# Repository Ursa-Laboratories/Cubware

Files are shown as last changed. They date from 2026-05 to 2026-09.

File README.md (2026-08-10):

# Cubware

Cubware is the repository for 3D-printed STL and design files for the open
source **Cub** and **CubOS** ecosystem. It holds the printable meshes,
source CAD (`.step`), preview assets, and any per-part documentation needed
to fabricate hardware for a Cub system.

## Configurations

Cub systems are built on top of an off-the-shelf SainSmart PROVER CNC
gantry. Cubware supports three configurations, and the repository is
organized by configuration:

| Configuration | Directory | Gantry hardware | Purpose |
| --- | --- | --- | --- |
| **Cub** | [`cub/`](cub/) | SainSmart PROVER 3030 | Single-instrument characterization. |
| **CubXL** | [`cubxl/`](cubxl/) | SainSmart PROVER 4030XL | Indentation experiments with a force sensor (ASMI) — see [ASMI_new](https://github.com/BU-KABlab/ASMI_new). |
| **CubXL+** | [`cubxl_plus/`](cubxl_plus/) | SainSmart PROVER 4030XL | Non-contact multi-instrument deck (PANDA) — see [PANDA-BEAR](https://github.com/BU-KABlab/PANDA-BEAR). |

## Layout

```
Cubware/
├── cub/                    # Cub (PROVER 3030)
│   ├── instrument_mounts/  #   uv_vis/, asmi/
│   └── labware/            #   well_plate_holder/, calibration_block/
├── cubxl/                  # CubXL (PROVER 4030XL, ASMI)
│   ├── instrument_mounts/  #   asmi/
│   └── labware/            #   well_plate_holder/, calibration_block/
├── cubxl_plus/             # CubXL+ (PROVER 4030XL, PANDA)
│   ├── deck/               #   polycarbonate_deck/
│   ├── instrument_mounts/  #   backboard/, vial_capper_decapper_mount/,
│   │                       #   raspberry_pi_mount/, potentiostat_mount/
│   └── labware/            #   well_plate_holder/, calibration_block/,
│                           #   vial_holder/, tip_rack_holder/
├── shared/                 # Parts used by every configuration
│                           #   (calibration_block/)
├── misc/                   # Parts not yet assigned to a configuration
├── documentation/          # Build guides and hardware assembly notes
├── tools/                  # CAD generation / QA scripts (FreeCAD)
└── scripts/                # Preview rendering helpers
```

Each part lives in its own folder so that it can carry its own README,
preview images, source CAD, and any other documentation it needs. Parts
shared by all three configurations (like the calibration block) live once
under `shared/`, with pointer READMEs in each configuration's tree.

## Folder conventions

Inside each part folder you may find:

| File | Purpose |
| --- | --- |
| `*.stl` | Printable mesh — what you send to the slicer. |
| `*.step` | Source CAD — editable in any parametric CAD tool. |
| `*.glb` | Web/local 3D preview. |
| `*.png` | Static preview image. |
| `*.yaml` | Optional labware config consumed by [CubOS](../cubos/). |
| `README.md` | Part-specific assembly, compatibility, and print notes. |

Not every folder has every file type — some parts are mesh-only, some are
CAD-only, and some labware additionally ship a YAML definition.

## Documentation

- [Vial Capper / Decapper Build Guide](documentation/vial-capper-decapper-build.md)
  covers the PANDA capper/decapper BOM, cap fabrication, vial-holder setup,
  Arduino wiring, and CubOS integration status.

## Adding a new part

1. Create a new folder under the configuration the part belongs to
   (`cub/`, `cubxl/`, or `cubxl_plus/`), inside the appropriate category
   (`instrument_mounts/`, `labware/`, or `deck/`), using a descriptive
   `snake_case` name. Parts used by every configuration go under
   `shared/`.
2. Drop in the `.stl` and/or `.step` files for the part.
3. Add a `README.md` covering: what the part is, what files are included,
   assembly steps, and compatibility (which Cub deck / hardware revision
   it fits).
4. Optionally include `.glb` and `.png` previews for quick visual reference.

## Related repos

- [CubOS](../cubos/) — control software for the Cub robot, which consumes
  the labware YAML definitions referenced here.

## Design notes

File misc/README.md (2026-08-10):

# Misc

Parts that are not (yet) assigned to a specific Cub configuration
(`cub/`, `cubxl/`, `cubxl_plus/`). When a part here is confirmed to
belong to a configuration, move it into that tree and give it a README.

| Part | Notes |
| --- | --- |
| `PAW-V2-Opentrons Temperature Module Mount/` | PAW-V2 (OT-2 era) temperature module mount. |
| `Para-Dox Well Plate Vial Cover_REV. 0.step` | Well plate vial cover. |
| `standard_96_position_photoredox_block_vial_retainer/` | Open-access vial retainer + gasket for the standard 96-position photoredox block; includes the `ursa_101960_retainer.py` parametric generator. |

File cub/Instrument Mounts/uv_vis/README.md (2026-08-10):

# UV-Vis Mount (Cub)

Mount for carrying the UV-Vis spectrometer probe on the **Cub**
gantry.

## Files

| File | Purpose |
| --- | --- |
| `3018 Mount_REV. 0 (3).step` | Source CAD for the mount. |

> **Note:** this STEP was uploaded as "3018 Mount" with no part page. It
> was identified as the Cub UV-Vis mount by process of elimination during
> the 2026-08-10 reorganization — if that's wrong, please move it and
> update this README.

## Compatibility

- Gantry: **Cub** (SainSmart PROVER 3030)

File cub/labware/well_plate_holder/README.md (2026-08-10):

# Cub Wellplate Holder

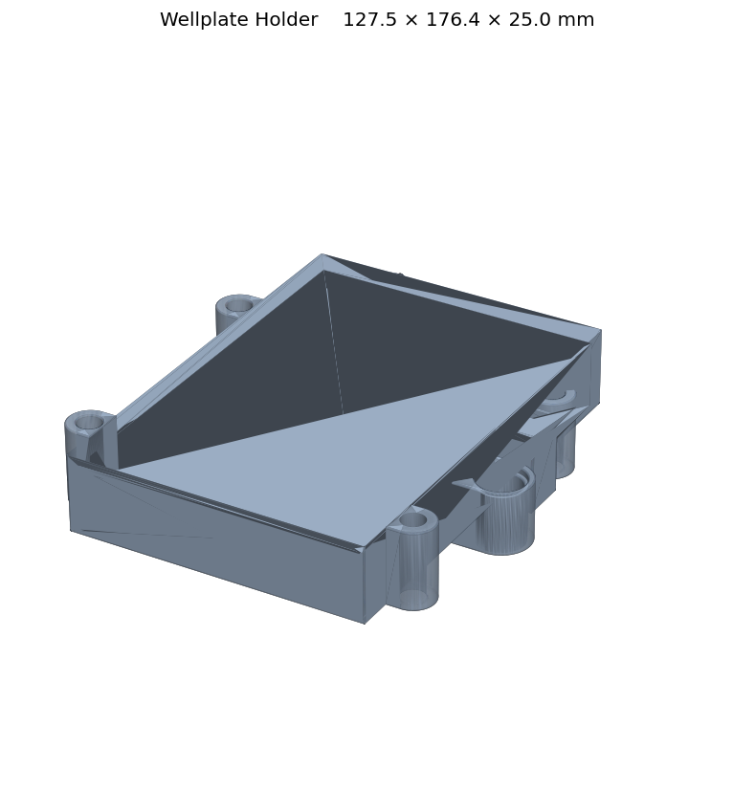
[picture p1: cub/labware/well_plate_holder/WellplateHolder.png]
Wellplate Holder preview


A 3D-printed holder for seating a standard wellplate on the **Cub**
configuration deck. This model is the Filmetrics-compatible variant,
used when the plate needs to be positioned for film-thickness measurements.

## Files

| File | Purpose |
| --- | --- |
| `WellplateHolder.stl` | Printable mesh of the wellplate holder. |
| `WellplateHolder.glb` | Web/local 3D preview. |

## Assembly

1. 3D-print `WellplateHolder.stl`.
2. Place on the deck in the intended wellplate slot.
3. Drop the wellplate into the holder cavity.

## Compatibility

- Deck: **Cub configuration only** (does not fit the Cub-XL deck)

## Previewing the 3D model

The `.glb` file can be opened in:

- macOS Finder Quick Look (spacebar)
- VS Code with a glTF viewer extension
- Any browser via the `index.html` page in the parent directory
  (`python -m http.server 8000` then open `http://localhost:8000/`)

## Regenerating the GLB file

From the parent directory:

```bash
python step_to_glb.py well_plate_holder
```

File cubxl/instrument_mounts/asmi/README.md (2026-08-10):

# ASMI Mounts (CubXL)

| Back | Front | Cap |
| --- | --- | --- |
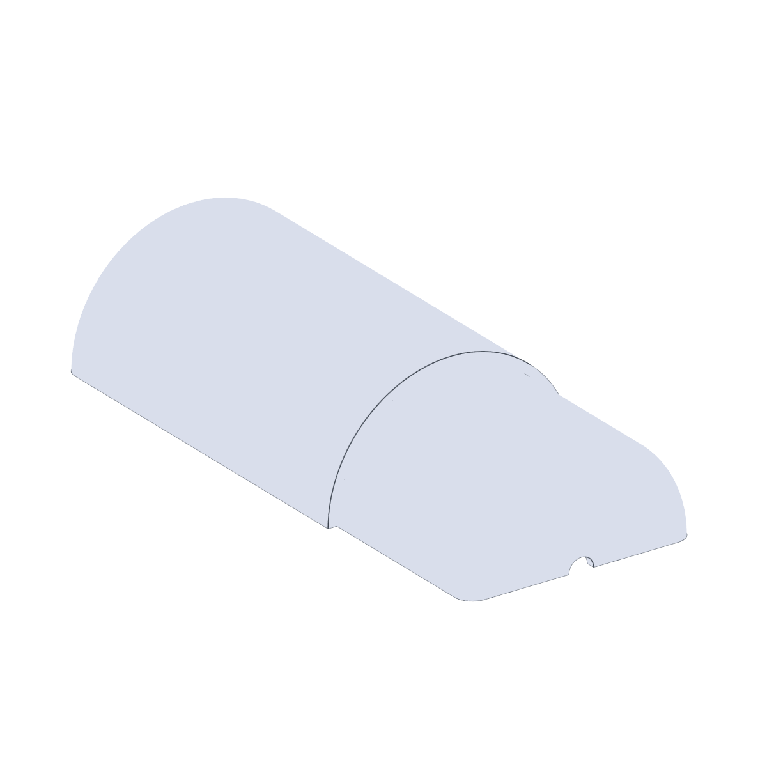
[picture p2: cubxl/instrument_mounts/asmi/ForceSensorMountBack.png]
Back
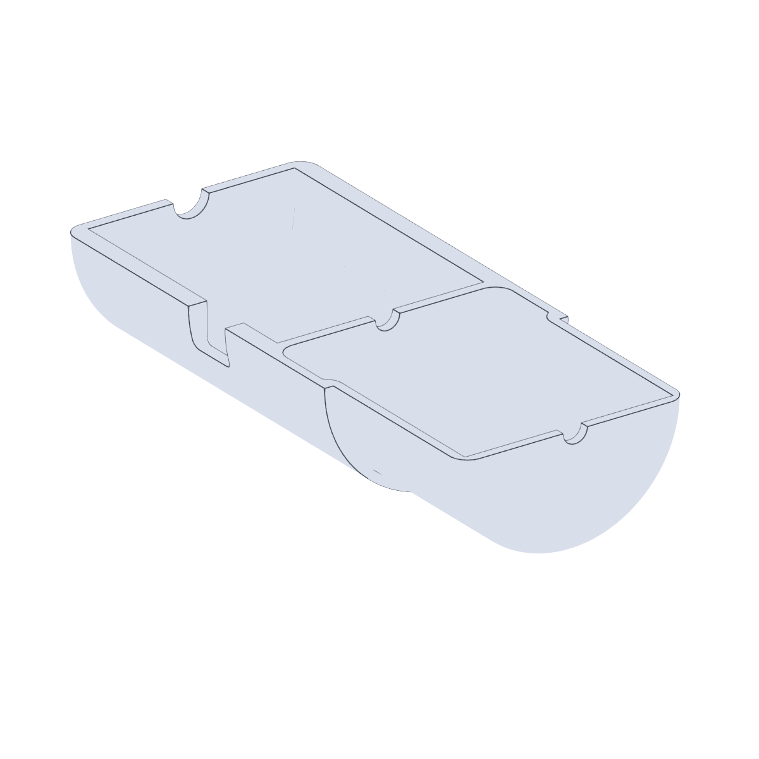
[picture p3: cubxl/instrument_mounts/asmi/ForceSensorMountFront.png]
Front
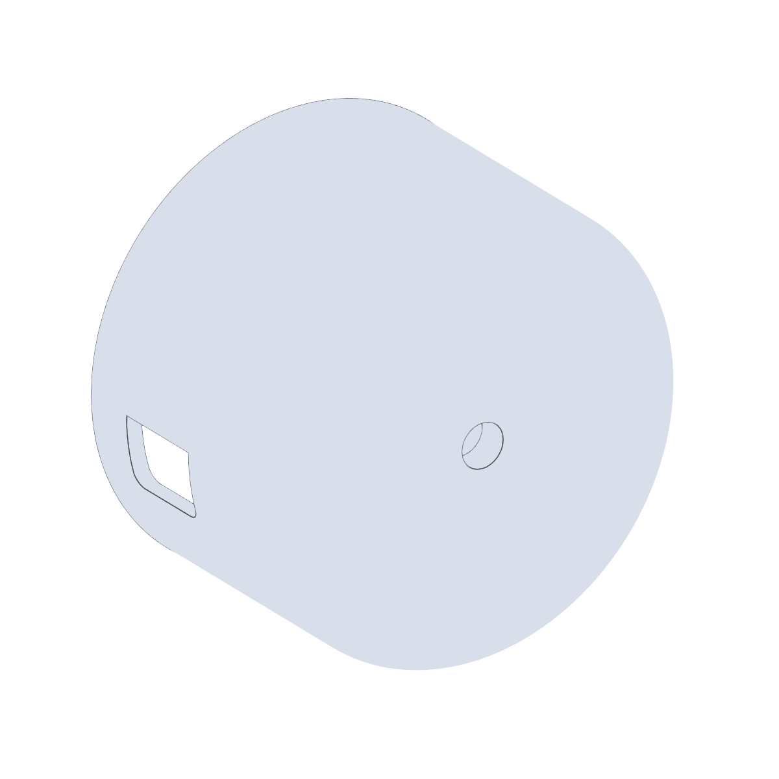
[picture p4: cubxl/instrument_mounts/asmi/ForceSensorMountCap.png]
Cap
|  |  |  |

3D-printed mounts for attaching a Vernier force sensor (and related ASMI
hardware) to the **CubXL** for the
[ASMI](https://github.com/BU-KABlab/ASMI_new) system.

## Files

| File | Purpose |
| --- | --- |
| `ForceSensorMountBack.stl` / `.step` | Back half of the sensor housing. |
| `ForceSensorMountFront.stl` / `.step` | Front half of the sensor housing. |
| `ForceSensorMountCap.stl` / `.step` | Cap that closes the housing once the sensor is seated. |
| `Vernier Go Direct Mount (Base)_REV. 3 (1).step` | Newer two-part Go Direct sensor mount — base. |
| `Vernier Go Direct Mount (Cover)_REV. 3 (1).step` | Newer two-part Go Direct sensor mount — cover. |
| `Heater Plate Holder_REV. 0.step` | Holder for the ASMI heater plate. |

Print all three ForceSensorMount parts; the `.step` files are the source
CAD if you need to modify the design. The REV. 0 Go Direct mount sized
for the Cub lives in
[`../../../cub/instrument_mounts/asmi/`](../../../cub/instrument_mounts/asmi/),
and the CubXL ASMI wellplate holder is under
[`../../labware/well_plate_holder/`](../../labware/well_plate_holder/).

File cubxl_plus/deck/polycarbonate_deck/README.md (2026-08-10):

# Panda Deck (Polycarbonate Base Plate)

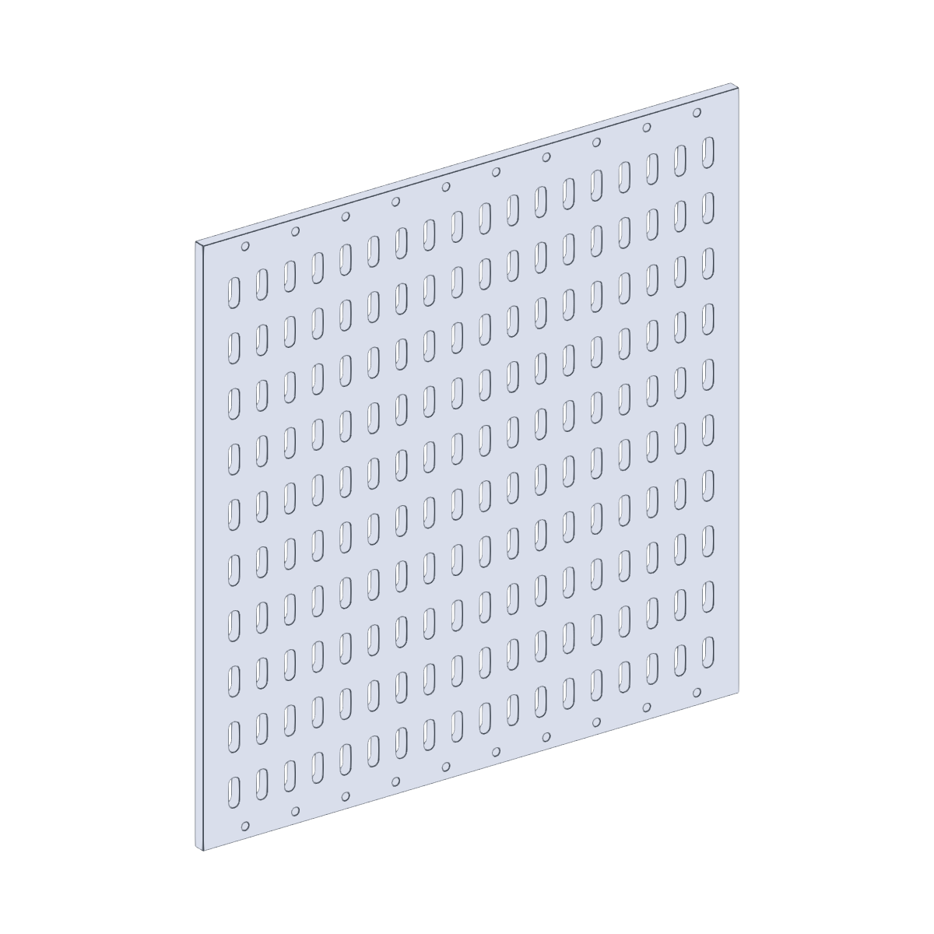
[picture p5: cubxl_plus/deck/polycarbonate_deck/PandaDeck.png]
Panda Deck preview


Base plate for the **CubXL+** intended for use with non-contact instruments.
Reproduces the deck layout of the original
[PANDA-BEAR](https://github.com/BU-KABlab/PANDA-BEAR) configuration, so any
labware and instrument positions defined for PANDA carry over to a CubXL+
built on this plate.

## Files

| File | Purpose |
| --- | --- |
| `PandaDeck.step` | Source CAD — edit this if you need to adjust hole patterns or footprint. |
| `PandaDeck.stl` | Mesh export of the same plate (e.g. for slicing or quick previews). |

## Material

Intended to be machined from **polycarbonate** sheet — hence the folder
name. STL is provided for convenience but the STEP is the authoritative
source for fabrication.

## Compatibility

- Deck: **CubXL+ only**
- Instruments: non-contact (no force/contact loading expected on the plate)

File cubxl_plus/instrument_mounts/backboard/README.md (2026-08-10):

# OT2 Backboard

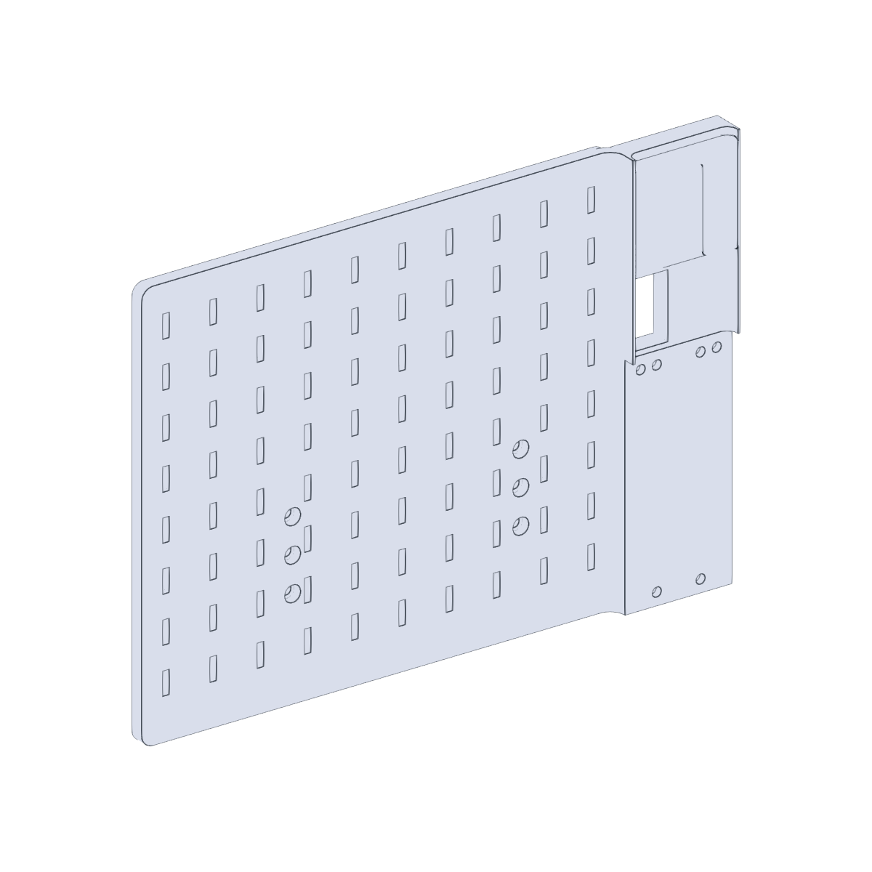
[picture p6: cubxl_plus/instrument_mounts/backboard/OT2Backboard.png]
OT2 Backboard preview


The OT2 backboard is the central mounting plate that bolts to the
Opentrons OT-2 frame and serves as the carrier for the other CubXL+
instrument mounts. The other PAW-V2 mounts in this directory all attach
to this backboard:

- [`../vial_capper_decapper_mount/`](../vial_capper_decapper_mount/) —
  electromagnet used to drive the vial capper/decapper.
- [`../raspberry_pi_mount/`](../raspberry_pi_mount/) —
  Raspberry Pi Camera Module 3 mount.
- [`../potentiostat_mount/`](../potentiostat_mount/) —
  ionic conductivity probe (potentiostat) mount.

## Files

| File | Purpose |
| --- | --- |
| `OT2Backboard.stl` | Backboard plate itself. |
| `Spacers.stl` | Spacers that set the standoff between the backboard and the OT-2 frame. |

## Previews

| Backboard | Spacers |
| --- | --- |
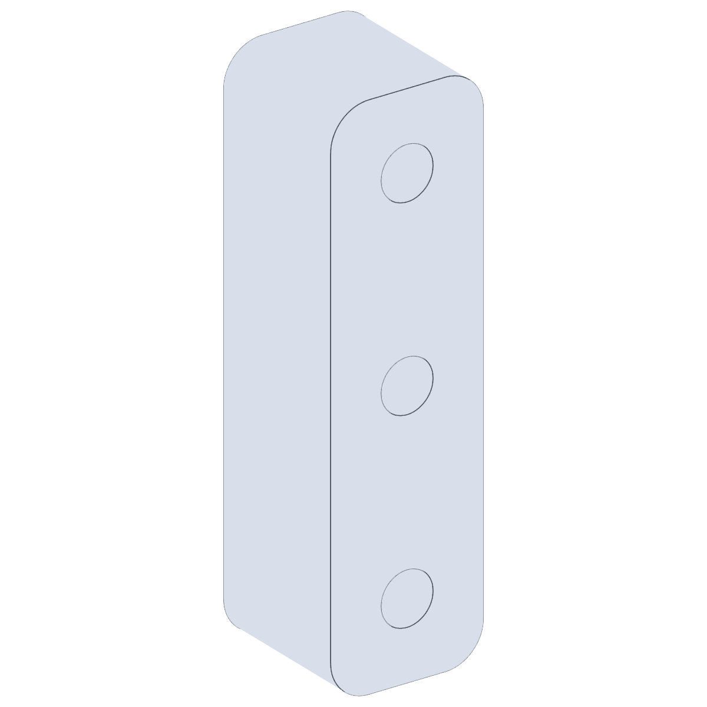
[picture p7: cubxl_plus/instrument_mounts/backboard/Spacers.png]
Spacers
| Backboard |  |

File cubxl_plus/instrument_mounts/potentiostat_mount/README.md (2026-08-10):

# Potentiostat (Ionic Conductivity Probe) Mount

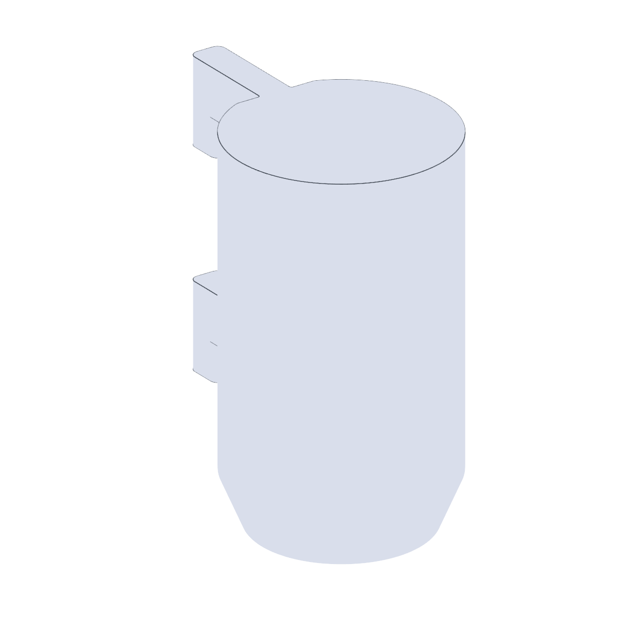
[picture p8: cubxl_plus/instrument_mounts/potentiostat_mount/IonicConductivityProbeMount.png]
Ionic conductivity probe mount preview


Mount for the ionic conductivity probe read by the potentiostat. Bolts
onto the [OT2 backboard](../backboard/).

## Files

| File | Purpose |
| --- | --- |
| `IonicConductivityProbeMount.stl` | Printable probe holder. |

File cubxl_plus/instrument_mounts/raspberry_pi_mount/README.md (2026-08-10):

# Raspberry Pi Camera Mount

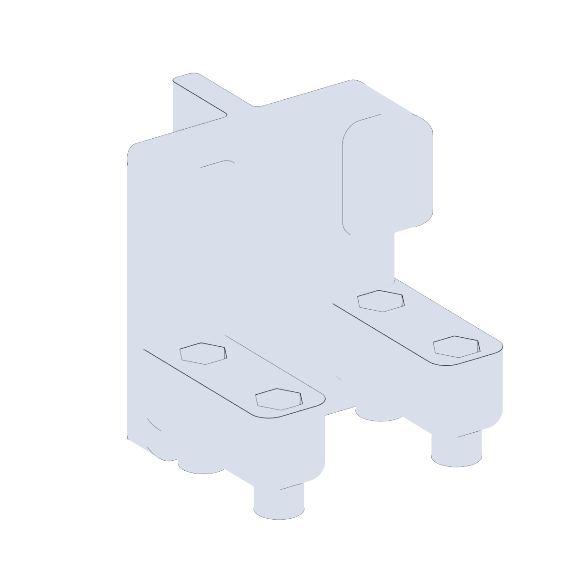
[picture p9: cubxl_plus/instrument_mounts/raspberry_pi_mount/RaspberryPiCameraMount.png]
RPi camera mount preview


Mount for a Raspberry Pi Camera Module 3. Bolts onto the
[OT2 backboard](../backboard/).

## Files

| File | Purpose |
| --- | --- |
| `RaspberryPiCameraMount.stl` | Printable camera housing. |

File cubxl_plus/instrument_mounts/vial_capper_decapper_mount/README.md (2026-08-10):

# Vial Decapper Mount

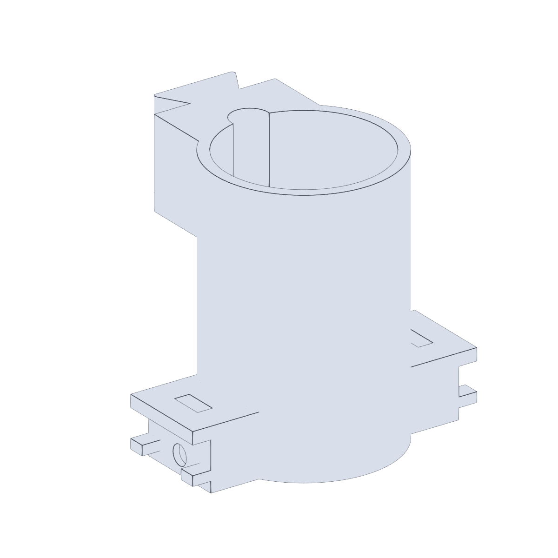
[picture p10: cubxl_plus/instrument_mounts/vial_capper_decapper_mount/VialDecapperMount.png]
Vial decapper mount preview


Mount that holds the electromagnet used to drive the vial
capper/decapper. Bolts onto the [OT2 backboard](../backboard/). See the
[Vial Capper / Decapper Build Guide](../../../documentation/vial-capper-decapper-build.md)
for the full assembly.

## Files

| File | Purpose |
| --- | --- |
| `VialDecapperMount.stl` | Printable electromagnet housing. |

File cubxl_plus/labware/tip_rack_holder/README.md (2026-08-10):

# Pipette Tip Rack

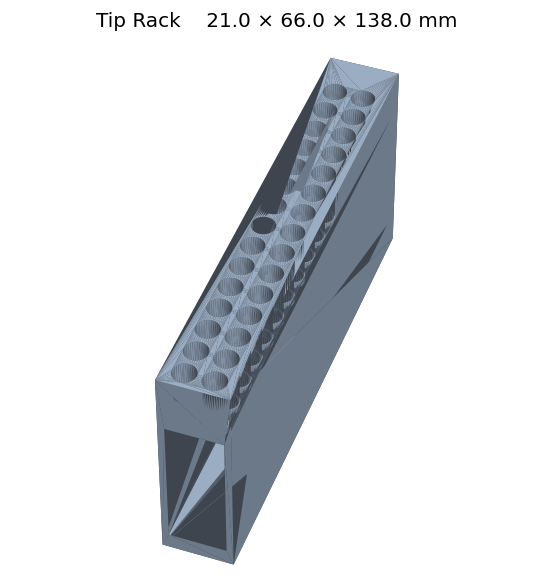
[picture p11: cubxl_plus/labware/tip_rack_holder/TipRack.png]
Tip Rack preview


A 3D-printed rack for holding disposable pipette tips on the PANDA-BEAR deck.
Maps to `cubos.src.deck.labware.tip_rack.TipRack`, which inherits from
`HolderLabware` and exposes a per-tip `tip_present` boolean flag for tracking
which tips are still loaded vs. consumed.

## Files

| File | Purpose |
| --- | --- |
| `TipRack.stl` | Printable mesh of the tip rack. |
| `TipRack.glb` | Web/local 3D preview. |
| `TipRack.png` | Static preview image. |
| `TipRack.yaml` | Labware config mapping to `TipRack`. Placeholder tip layout — fill in before use. |

## Assembly

1. 3D-print `TipRack.stl`.
2. Place on the deck in the intended tip-rack slot.

## Compatibility

- Deck: PANDA-BEAR **CubXL+ only** (does not fit the Cub deck)

## Previewing the 3D model

The `.glb` file can be opened in:

- macOS Finder Quick Look (spacebar)
- VS Code with a glTF viewer extension
- Any browser via the `index.html` page in the parent directory
  (`python -m http.server 8000` then open `http://localhost:8000/`)

## Regenerating the GLB file

From the parent directory:

```bash
python step_to_glb.py tip_rack_holder
```

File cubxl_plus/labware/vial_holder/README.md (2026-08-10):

# 9-Vial Holder (20 mL)

| Holder | Key |
| --- | --- |
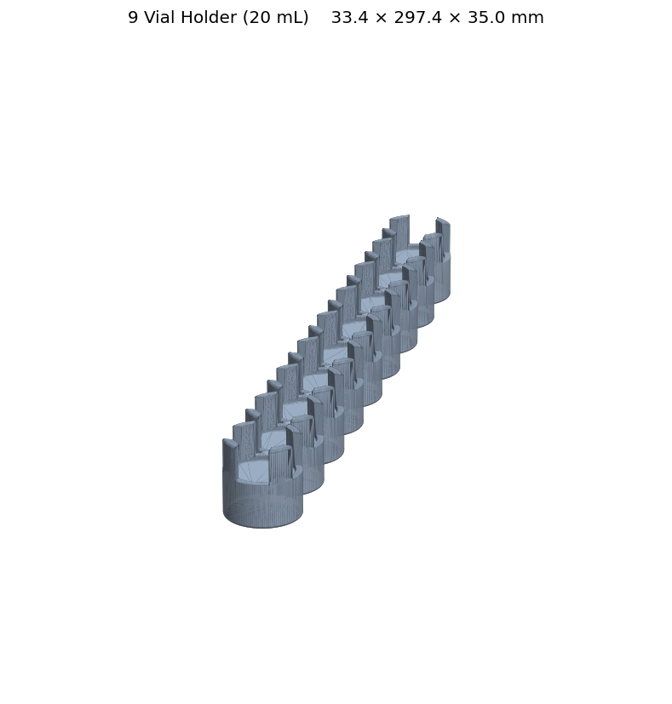
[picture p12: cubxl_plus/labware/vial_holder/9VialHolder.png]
Vial Holder preview
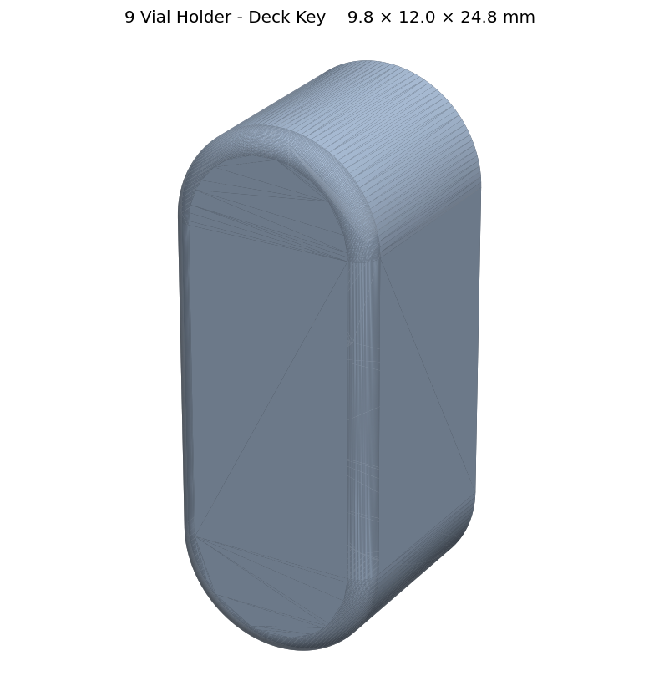
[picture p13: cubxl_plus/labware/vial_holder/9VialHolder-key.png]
Vial Holder key preview
|  |  |

A 3D-printed deck accessory that holds nine standard 20 mL vials on the
PANDA-BEAR **CubXL+** deck.

## Files

| File | Purpose |
| --- | --- |
| `9VialHolder.step` | The main holder body. Tight-fit cavities for nine standard 20 mL vials. |
| `9VialHolder-key.step` | A small "key" insert that locks the holder into place on the CubXL+ deck. |
| `9VialHolder.glb` | Web/local 3D preview of the holder. |
| `9VialHolder-key.glb` | Web/local 3D preview of the key insert. |

## Assembly

1. 3D-print both `.step` files.
2. Superglue the printed **key** into the matching slot on the **holder**.
3. Snap the assembled holder onto the CubXL+ deck.

The key is what keeps the holder locked to the deck, so make sure the glue
joint is fully cured before loading vials.

## Compatibility

- Vials: standard 20 mL (tight fit — no adapters needed)
- Deck: PANDA-BEAR **CubXL+ only** (does not fit the Cub deck)

## Previewing the 3D models

The `.glb` files can be opened in:

- macOS Finder Quick Look (spacebar)
- VS Code with a glTF viewer extension
- Any browser via the `index.html` page in the parent directory
  (`python -m http.server 8000` then open `http://localhost:8000/`)

## Regenerating the GLB files

From the parent directory:

```bash
python step_to_glb.py vial_holder
```

See `../step_to_glb.py` for options (tessellation tolerance, batch mode, etc.).

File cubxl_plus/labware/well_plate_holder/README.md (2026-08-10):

# Panda SBS Wellplate Holder

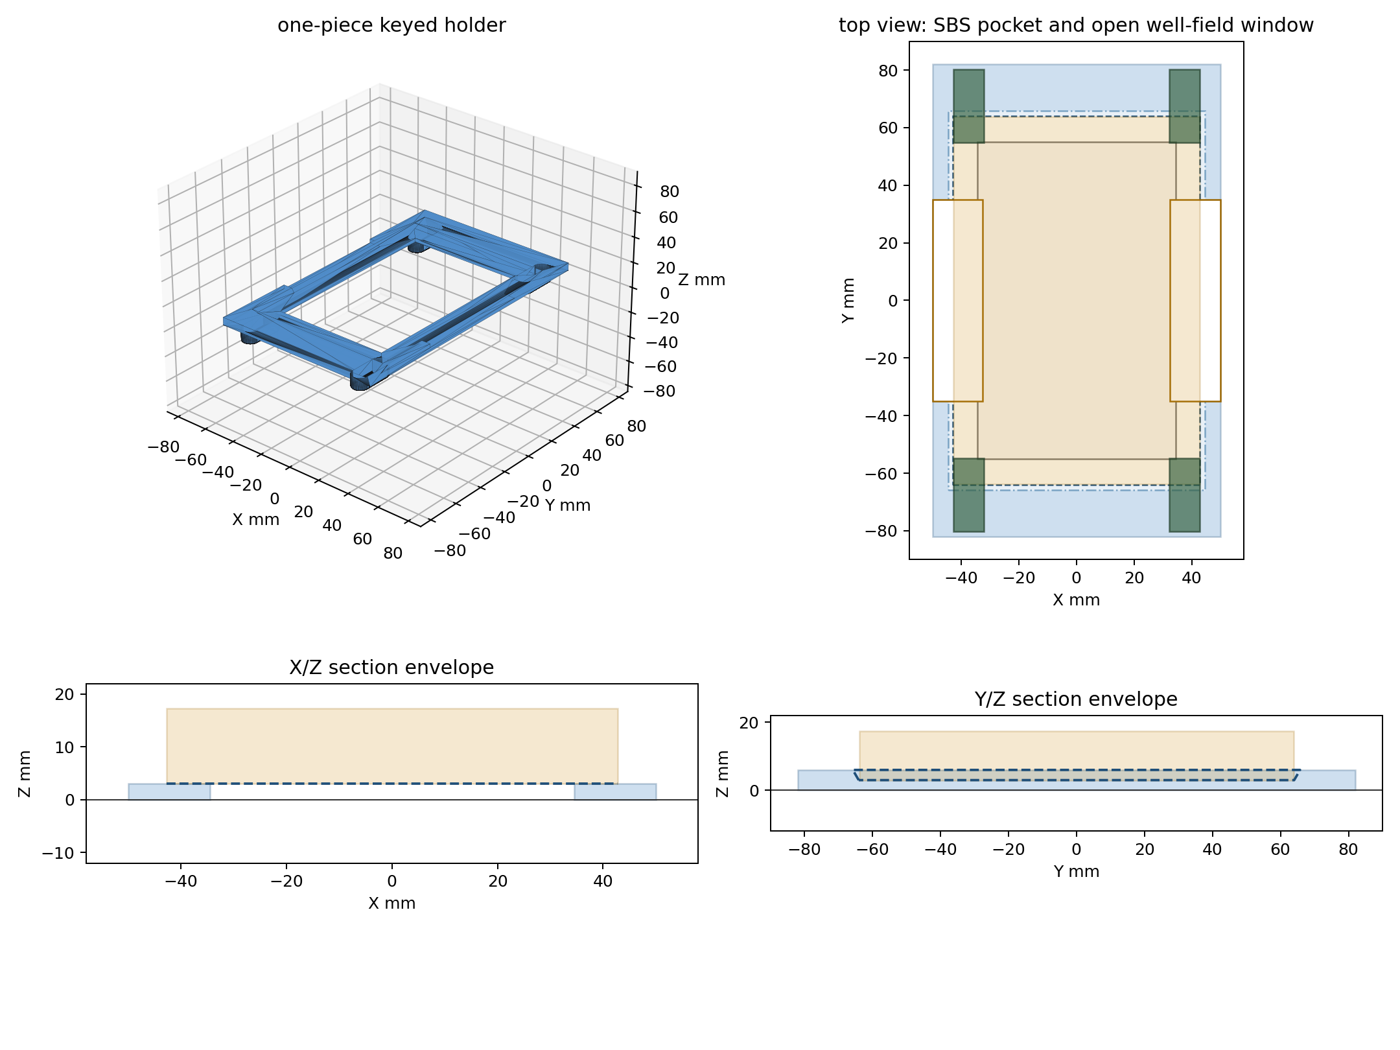
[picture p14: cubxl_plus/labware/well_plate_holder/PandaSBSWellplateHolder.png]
Panda SBS Wellplate Holder preview


A keyed 3D-printed holder for seating a standard SBS/ANSI 96-well plate on
`cubxl_plus/deck/polycarbonate_deck/PandaDeck.step`.

This replaces the visually incompatible legacy `ursa_wellplate_holder` pattern
for the PandaDeck by using the same deck key geometry as
`../vial_holder/9VialHolder-key.step`.

## Files

| File | Purpose |
| --- | --- |
| `PandaSBSWellplateHolder.step` | Manufacturing/source CAD for the 6 mm holder with a 60 degree lead-in and 70 mm long-side gripper gaps. |
| `PandaSBSWellplateHolder.stl` | Printable mesh exported from the STEP, pre-oriented with the top/pocket face on the build plate and keys printed last. |
| `PandaSBSWellplateHolder.3mf` | Basic 3MF export of the printable mesh. |
| `PandaSBSWellplateHolder.gcode.3mf` | Sliced 3MF/G-code package for the current holder. |
| `PandaSBSWellplateHolder-deck-fit.step` | QA assembly: PandaDeck, keyed holder, and SBS plate envelope. |
| `PandaSBSWellplateHolder.png` | Holder geometry preview. |
| `PandaSBSWellplateHolder-deck-fit.png` | Visual deck-fit preview. |
| `PandaSBSWellplateHolder-print-orientation.png` | Visual preview of the STL print orientation. |
| `PandaSBSWellplateHolder.yaml` | CubOS-style labware metadata for the physical holder. |

## Geometry

- SBS plate footprint: 85.48 mm x 127.76 mm, oriented with the 12-column
  direction along deck Y.
- Pocket clearance: 0.30 mm total over the nominal SBS footprint.
- Holder body footprint: 100.0 mm x 164.0 mm.
- Plate underside seat height: 3.0 mm above the holder body bottom.
- Holder body height: 6.0 mm.
- Printed side-wall height above plate seat: 3.0 mm.
- Lead-in angle: 60 degrees from the horizontal seat plane.
- Tapered top opening: 89.24 mm x 131.52 mm, narrowing to the 85.78 mm x
  128.06 mm seated pocket.
- Long-side gripper gaps: centered 70.0 mm openings in both raised long-side
  rails. The 3.0 mm seat/base remains connected below those openings so the
  holder stays one printable solid.
- Plate rim/surface height: 17.35 mm above the holder body bottom.
- Deck keys: four integral copies of `9VialHolder-key.step`.
- Key layout: corners of a 4-by-4 PandaDeck insert block.

The pocket is intentionally tighter than a universal worst-case SBS carrier.
The previous generator used 0.65 mm total clearance; the SBS width constant was
also 0.01 mm under the nominal standard value, which is negligible compared
with the clearance. Use `--plate-clearance` if a specific printer/material or
plate vendor needs a looser pocket.

The generated deck-fit assembly places the local holder origin at deck
`(90.0, -112.5, 10.0)` so the four key centers land on these PandaDeck slots:

| Deck X | Deck Y |
| --- | --- |
| 52.5 | -45.0 |
| 127.5 | -45.0 |
| 52.5 | -180.0 |
| 127.5 | -180.0 |

## Printing

- Do not scale.
- Recommended material: PETG, ASA, or a dimensionally stable PLA+.
- `PandaSBSWellplateHolder.stl` is already oriented for printing: the
  top/pocket face is on the build plate and the four keys point upward so they
  are printed last. Use a brim if bed contact is marginal.
- Use at least 4 perimeters/walls and 30% infill for a rigid frame.
- If your printer shows elephant's-foot growth, use first-layer or XY
  compensation before judging deck-key fit.

## QA

Generated and checked with FreeCAD 1.0.2:

```bash
PYTHONPATH=/Applications/FreeCAD.app/Contents/Resources/lib \
  /Applications/FreeCAD.app/Contents/Resources/bin/python \
  tools/build_panda_sbs_wellplate_holder.py

PYTHONPATH=/Applications/FreeCAD.app/Contents/Resources/lib \
  /Applications/FreeCAD.app/Contents/Resources/bin/python \
  tools/render_panda_holder_previews.py

PYTHONPATH=/Applications/FreeCAD.app/Contents/Resources/lib \
  /Applications/FreeCAD.app/Contents/Resources/bin/python \
  tools/inspect_geometry.py \
  cubxl_plus/labware/well_plate_holder/PandaSBSWellplateHolder.step \
  cubxl_plus/labware/well_plate_holder/PandaSBSWellplateHolder.stl

PYTHONPATH=/Applications/FreeCAD.app/Contents/Resources/lib \
  /Applications/FreeCAD.app/Contents/Resources/bin/python \
  tools/check_panda_holder_fit.py
```

The CAD checker verifies:

- The STEP is one valid closed solid.
- The STL is a solid mesh.
- Holder/PandaDeck boolean intersection volume is 0.0 mm^3.
- SBS plate envelope/holder boolean intersection volume is 0.0 mm^3.

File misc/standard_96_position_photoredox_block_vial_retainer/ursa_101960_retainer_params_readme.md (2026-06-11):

# Ursa 101960 Open-Access Vial Retainer

Open-access anti-lift vial retainer and optional gasket for the Analytical Sales
101960 Standard 96-Position Photoredox Reaction Block. The retainer is intended
to hold 8 mm OD vial lips down during indentation testing while leaving each
vial center open for the probe.

This is not a hermetic chemistry seal. It is a mechanical vial anti-lift cover
with optional compliant gasket features.

## Files

| File | Purpose |
| --- | --- |
| `ursa_101960_retainer.py` | Parameterized CadQuery 2.x source. |
| `ursa_101960_open_access_vial_retainer.step` | Full 96-position rigid retainer. |
| `ursa_101960_open_access_gasket.step` | Thin matching gasket. |
| `ursa_101960_3x4_test_coupon.step` | 3-column x 4-row retention test coupon. |

## Coordinate System

- Origin: center of the cover footprint in X/Y.
- X axis: 12-column vial direction.
- Y axis: 8-row vial direction.
- Z axis: upward.
- Rigid retainer underside is Z=0; underside bosses extend downward to negative Z.
- Units: millimeters only.

## Dimension Table

| Name | Value (mm) | Source | Confidence | Notes |
| --- | ---: | --- | --- | --- |
| Overall footprint length | 127.80 | explicit PDF dimension | high | 5.030 in [127.8 mm] |
| Overall footprint width | 85.50 | explicit PDF dimension | high | 3.365 in [85.5 mm] |
| Outer corner radius | 5.50 | explicit PDF dimension | high | R0.217 in [R5.5 mm] |
| Vial array | 12 x 8 = 96 | explicit PDF dimension | high | drawing row/column labels |
| Vial pitch X | 9.00 | explicit PDF dimension | high | 0.354 in [9.0 mm] |
| Vial pitch Y | 9.00 | explicit PDF dimension | high | 0.354 in [9.0 mm] |
| Left edge to first vial center | 14.40 | explicit PDF dimension | high | 0.566 in [14.4 mm] |
| Top edge to first vial center | 11.20 | explicit PDF dimension | high | 0.443 in [11.2 mm] |
| Holes in lid | 4.00 | explicit PDF dimension | high | 0.157 in [4.0 mm] |
| Holes in bottom | 6.00 | explicit PDF dimension | high | 0.236 in [6.0 mm] |
| Thermocouple hole diameter | 3.30 | explicit PDF dimension | high | 0.130 in [3.3 mm] |
| Height with vials | 46.20 | explicit PDF dimension | high | 1.820 in [46.2 mm] |
| Section dimension | 6.10 | explicit PDF dimension | high | 0.241 in [6.1 mm] |
| Section dimension | 5.10 | explicit PDF dimension | high | 0.202 in [5.1 mm] |
| OEM screw center X | 58.39 | inferred from scaled PDF geometry | medium-high | symmetric side clamp screw centers |
| OEM screw center Y | 18.00 | inferred from scaled PDF geometry | medium-high | symmetric side clamp screw centers |
| OEM screw head/counterbore diameter | 12.70 | inferred from scaled PDF geometry | medium | visible head rings vary about 12.3-12.7 mm |
| OEM screw clearance diameter | 5.20 | user-chosen design parameter | low | PDF does not label screw shank |
| OEM screw counterbore depth | 1.20 | user-chosen design parameter | low | thin printed cover default |
| Accessory 6-32 hole center X | 58.39 | inferred from scaled PDF geometry | high | corner threaded-hole locations |
| Accessory 6-32 hole center Y | 37.24 | inferred from scaled PDF geometry | high | corner threaded-hole locations |
| Accessory through-clearance diameter | 3.70 | user-chosen design parameter | medium | clearance for #6 / 6-32 fastener |
| Thermocouple hole center X | 58.39 | inferred from scaled PDF geometry | medium-high | upper-right thermocouple hole |
| Thermocouple hole center Y | 29.24 | inferred from scaled PDF geometry | medium-high | upper-right thermocouple hole |
| Rigid retainer thickness | 2.50 | user-chosen design parameter | medium | printable default |
| Access-hole diameter | 6.70 | user-chosen design parameter | medium | parameter `access_d`, valid 5.8-7.2 mm |
| Underside boss OD | 8.30 | user-chosen design parameter | medium | gentle vial-lip bearing land |
| Underside boss height | 0.40 | user-chosen design parameter | medium | set to 0 to disable |
| Gasket thickness | 0.80 | user-chosen design parameter | medium | TPU/silicone default |

## Extraction Notes

The PDF text layer contains the explicit inch and millimeter dimensions listed
above. The top view is drawn at 1:1 scale, so vector coordinates were calibrated
using 72 PDF points per inch and checked against the labeled 127.8 mm length,
85.5 mm width, and 9.0 mm vial pitch.

The vial-grid vector centers produce:

- 96 centers.
- X pitch: 8.996 to 9.017 mm, rounded to the explicit 9.0 mm design value.
- Y pitch: 8.996 to 9.017 mm, rounded to the explicit 9.0 mm design value.
- First vial center offset from left edge: 14.38 mm, matching 14.4 mm.
- First vial center offset from top edge: 11.25 mm, matching 11.2 mm.

## Dimensions To Confirm Before Production

Measure these with calipers on the actual block before production use:

- OEM screw shank / through-clearance diameter. The PDF shows screw head rings
  but does not label the screw shank.
- OEM screw counterbore depth. The 1.2 mm default is chosen for a 2.5 mm printed
  retainer, not extracted from the PDF.
- OEM screw head/counterbore diameter. The visible vector rings vary slightly
  across the four screws and sit very close to the side edge.
- Vial lip height and lip OD for the exact #884001 vial lot.
- Whether the thermocouple hole should remain open for the specific test setup.

## Design Parameters

- `access_d = 6.7 mm`, valid range 5.8 to 7.2 mm.
- `vial_od = 8.0 mm`.
- `boss_od = 8.3 mm`.
- `boss_id = access_d`.
- `boss_height = 0.4 mm`; set to 0 to disable underside bosses.
- Minimum web between neighboring access holes is checked as `pitch - access_d`
  and must be at least 1.5 mm.
- Gasket hole diameter is `access_d + 0.2 mm`.

## Print And Assembly

- Print the rigid retainer flat.
- Avoid supports if possible.
- Rigid retainer materials: PETG, nylon, PC, or aluminum if machined later.
- Gasket materials: TPU, laser-cut silicone, or similar compliant sheet.
- Do not crush glass vials.
- Use spacers, shoulder screws, or controlled screw torque.
- Validate on the 3 x 4 coupon first using the worst-case sticky hydrogel
  pull-off condition.

## Regenerating STEP Files

```bash
python ursa_101960_retainer.py
```

The script prints the parameter table and lists the mounting dimensions inferred
from PDF geometry before exporting the STEP files.

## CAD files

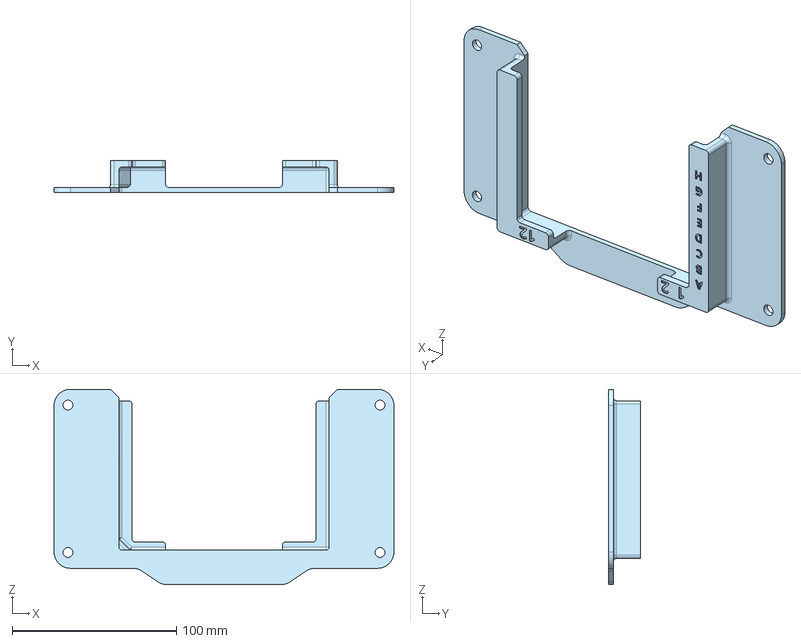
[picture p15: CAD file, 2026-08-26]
cubxl/labware/CubXL - ASMI Wellplate Holder/CubXL - ASMI Wellplate Holder_REV. 0 (1).step
207.0 x 19.5 x 119.0 mm

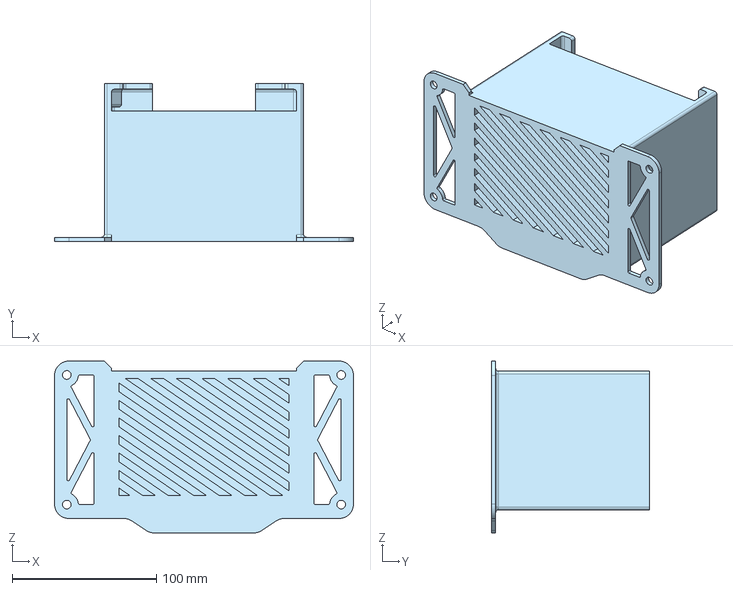
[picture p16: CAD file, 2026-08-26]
cubxl/labware/CubXL - ASMI Wellplate Holder/CubXL - ASMI Wellplate Holder_REV. 1 (4).step
207.0 x 109.5 x 119.0 mm

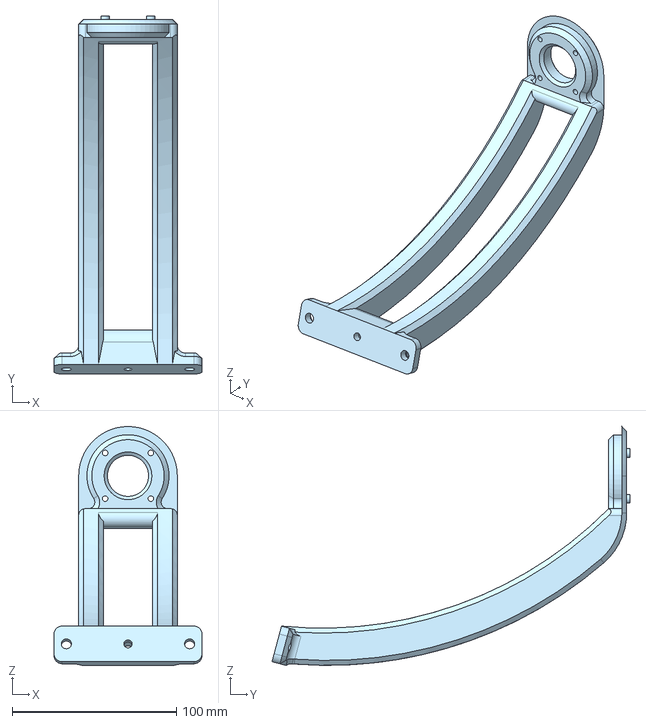
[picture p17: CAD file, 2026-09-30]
cub/Instrument Mounts/Cub - 2.0 Megapixel USB Camera Mount/2.0 Megapixel USB X Camera Mount_REV. 0.step
90.0 x 217.8 x 145.4 mm

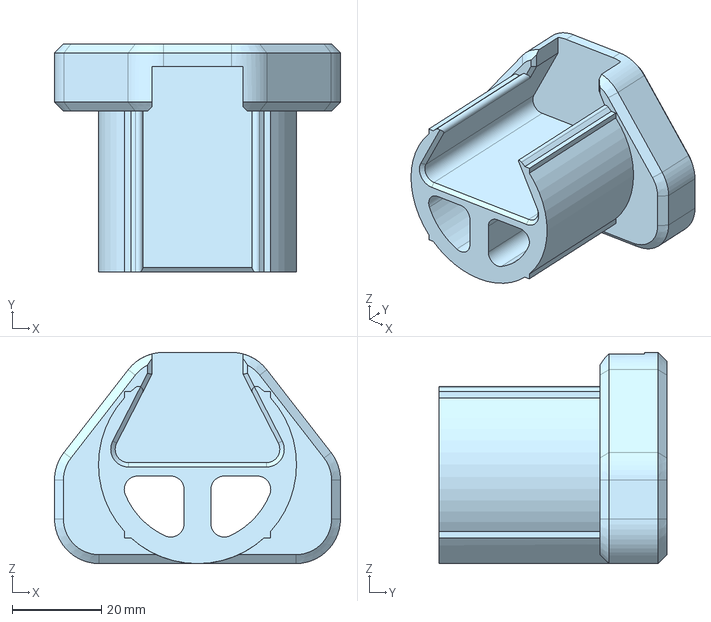
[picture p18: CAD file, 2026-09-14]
cub/Instrument Mounts/Cub - Vernier Go Direct Mount/Cub - 3018 Mount_REV. 0.step
64.0 x 51.0 x 47.3 mm

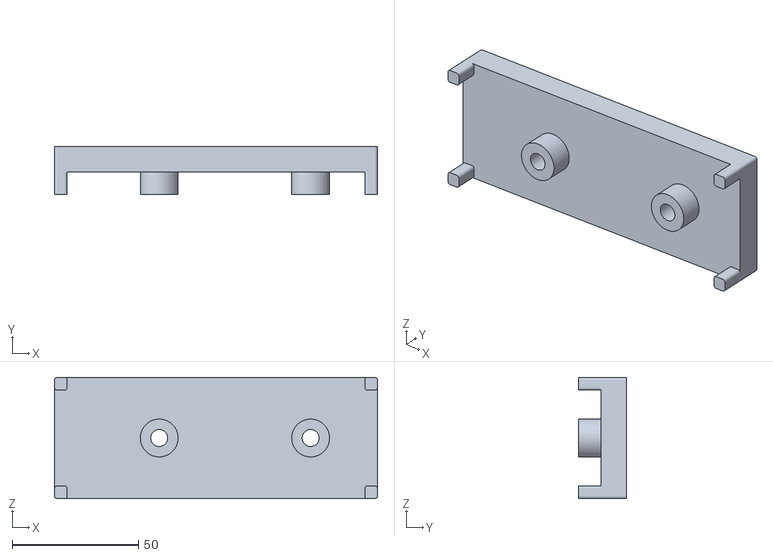
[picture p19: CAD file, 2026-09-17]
cub/labware/Color matching_vial holders_base.stl
128.0 x 19.0 x 48.0

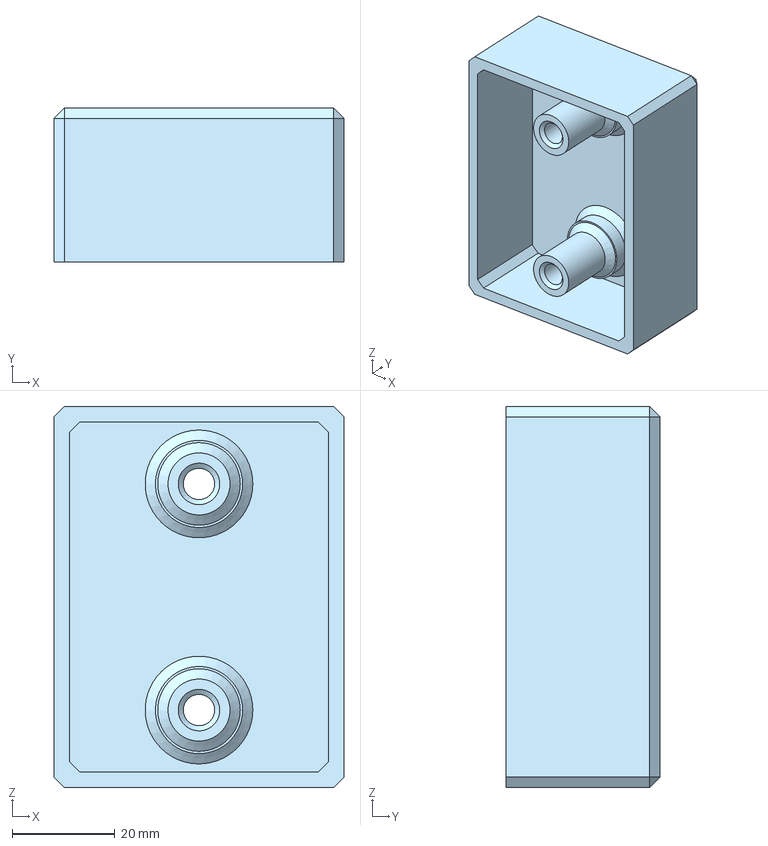
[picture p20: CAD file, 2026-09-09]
cub/labware/Cub - 100uL Pipette Tip Rack/100uL Pipette Tip Rack Mounting Base_REV. 0.step
56.5 x 30.0 x 74.3 mm

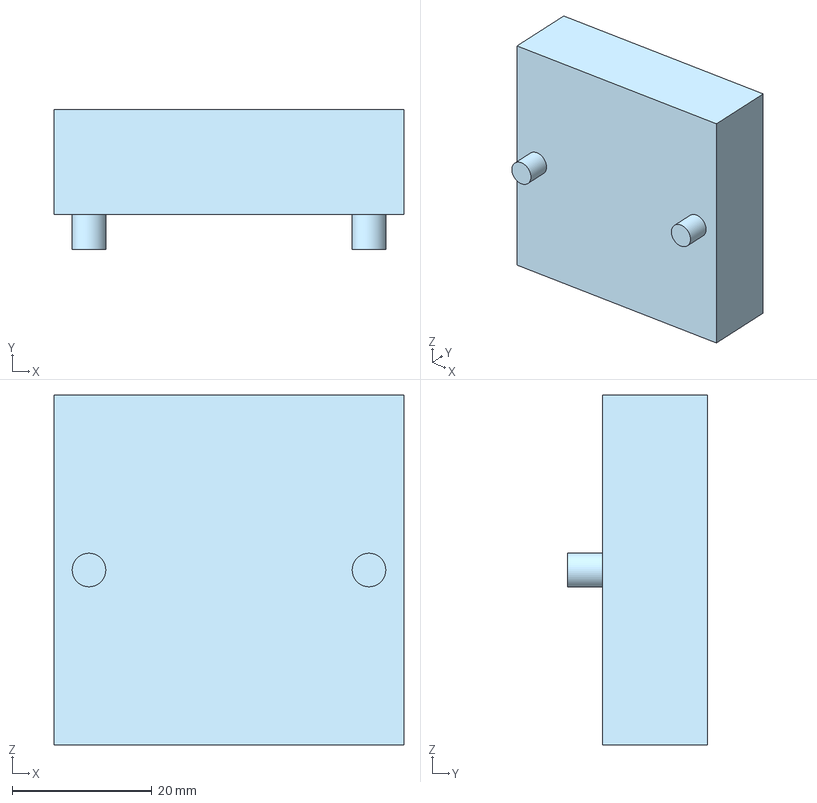
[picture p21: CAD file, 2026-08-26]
cub/labware/Cub - Calibration Block/Calibration Base (Cub)_REV. 0.step
50.0 x 20.0 x 50.0 mm

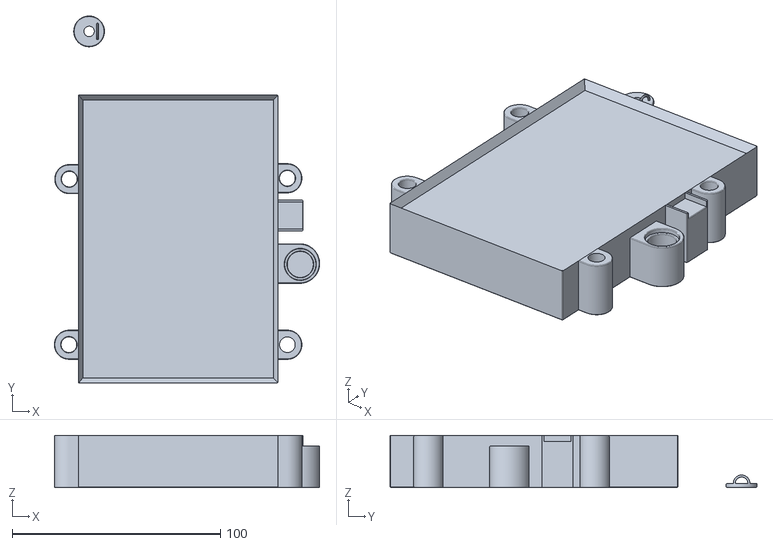
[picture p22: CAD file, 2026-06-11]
cub/labware/well_plate_holder/WellplateHolder.stl
127.5 x 176.4 x 25.0

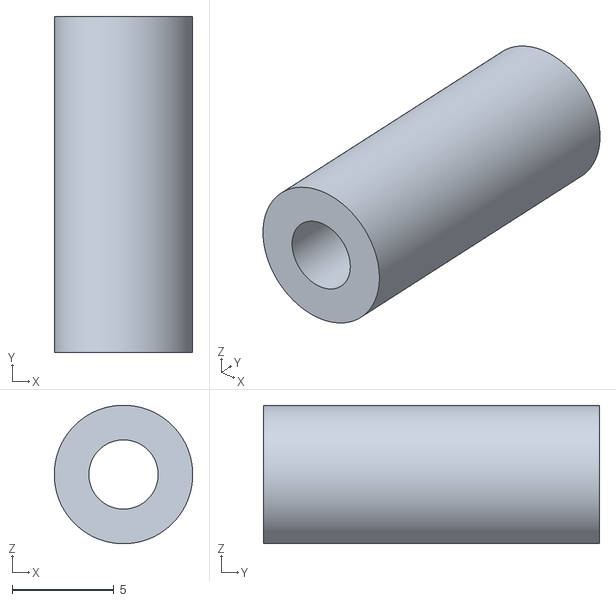
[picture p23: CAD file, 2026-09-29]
cub/Upgrades/Cub - X-Limit Switch Riser (extended Z)/Cub - X-Limit Switch Riser (extended Z)_REV. 0.stl
6.80 x 16.5 x 6.80

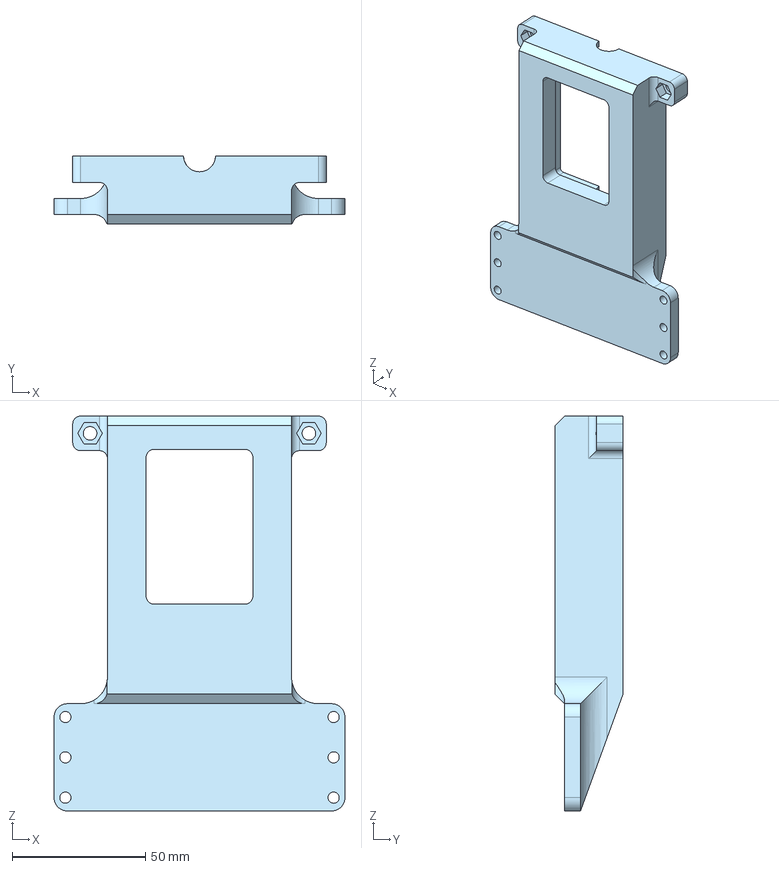
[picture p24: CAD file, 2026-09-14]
cubxl/instrument_mounts/asmi/CubXL - Vernier Go Direct Mount/CubXL - Vernier Go Direct Mount (Base)_REV. 4.step
109.0 x 25.6 x 148.0 mm

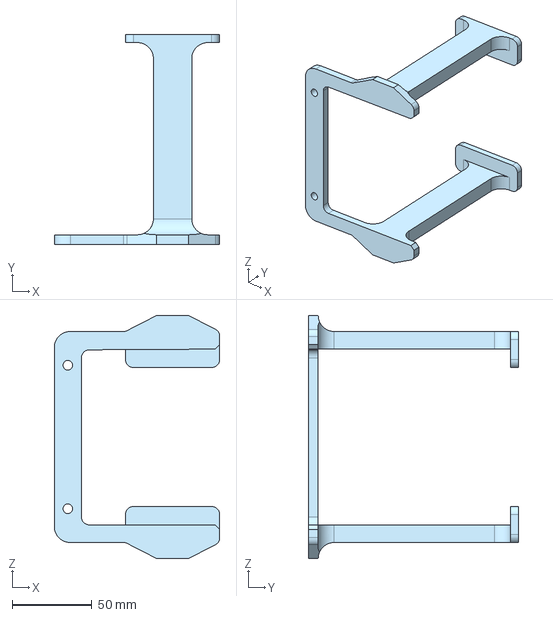
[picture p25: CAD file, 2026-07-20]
cubxl/instrument_mounts/asmi/Heater Plate Holder_REV. 0.step
103.5 x 131.2 x 152.0 mm

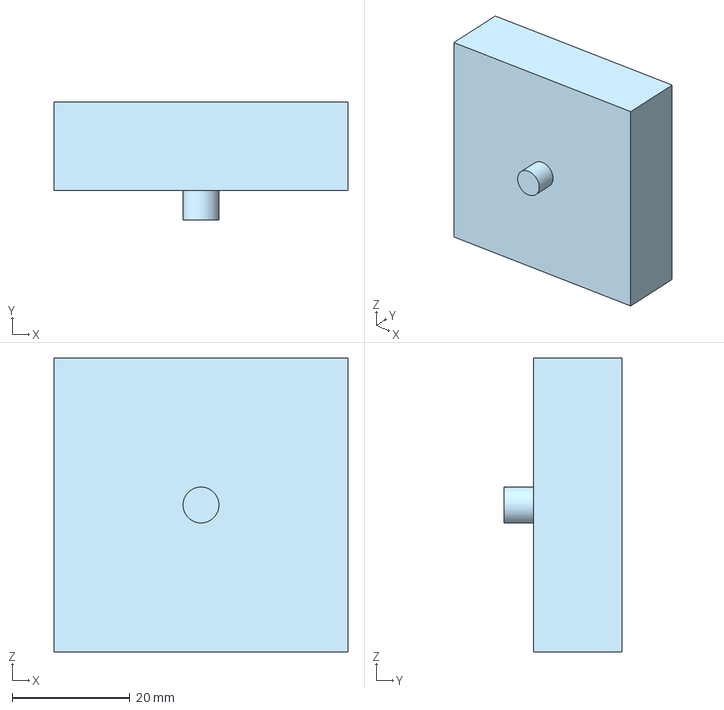
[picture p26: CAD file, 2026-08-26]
cubxl/labware/CubXL - Calibration Block/Calibration Base (CubXL)_REV. 0.step
50.0 x 20.0 x 50.0 mm

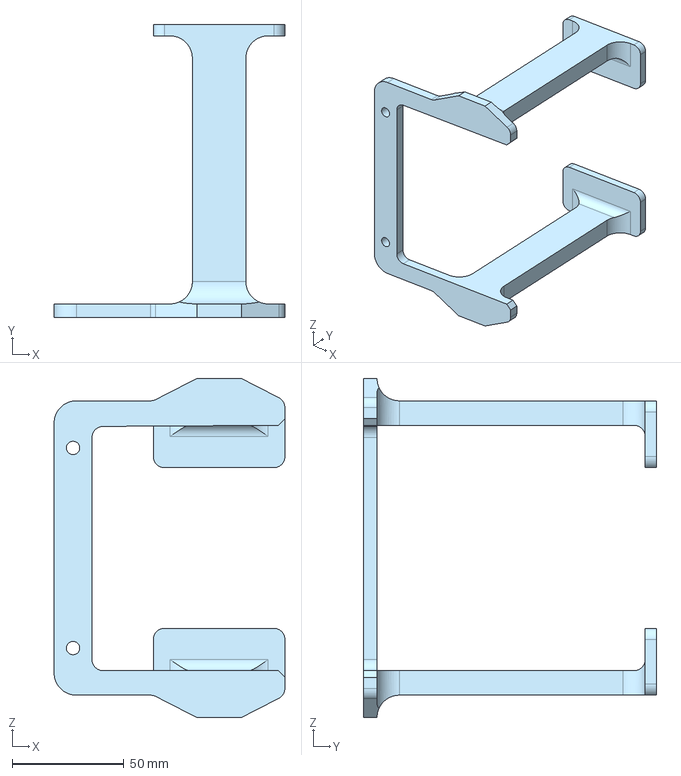
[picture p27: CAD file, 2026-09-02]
cubxl/labware/CubXL - Hamilton Heater Cooler Plate Holder/Hamilton Heater Cooler Plate Holder_REV. 0.step
103.5 x 131.2 x 152.0 mm

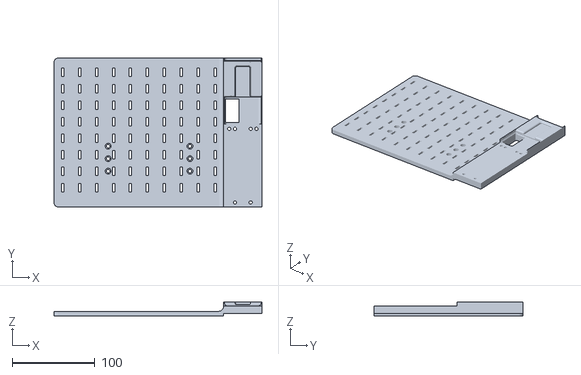
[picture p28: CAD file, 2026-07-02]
cubxl_plus/instrument_mounts/backboard/PAW-V2 - OT2Mount_REV. 1 - OT2Mount.stl
251.6 x 180.1 x 17.5

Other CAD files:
cub/Instrument Mounts/uv_vis/3018 Mount_REV. 0 (3).step
cubxl_plus/instrument_mounts/potentiostat_mount/IonicConductivityProbeMount.stl
cubxl_plus/instrument_mounts/raspberry_pi_mount/RaspberryPiCameraMount.stl
cub/Instrument Mounts/Cub - 2.0 Megapixel USB Camera Mount/2.0 Megapixel USB X Camera Mount_REV. 0.stl
cub/Instrument Mounts/Cub - 2.0 Megapixel USB Camera Mount/2.0 Megapixel USB Z Camera Mount_REV. 0.step
cub/Instrument Mounts/Cub - 2.0 Megapixel USB Camera Mount/2.0 Megapixel USB Z Camera Mount_REV. 0.stl
cub/Instrument Mounts/Cub - Vernier Go Direct Mount/Cub - Vernier Go Direct Mount (Base)_REV. 0.step
cub/Instrument Mounts/Cub - Vernier Go Direct Mount/Cub - Vernier Go Direct Mount (Cover)_REV. 0.step
cub/labware/Color matching_vial holders.stl
cub/labware/Color matching_vial holders_2.stl
cub/labware/ColorMatching_pipette tip box new.stl
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

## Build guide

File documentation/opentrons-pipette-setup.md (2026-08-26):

# Opentrons OT-2 Pipette Setup Guide

This page consolidates the current build, wiring, calibration, and CubOS
integration notes for using an Opentrons OT-2 electronic pipette on a PANDA/Cub
gantry. It covers the PAW/OT2 mechanical mount, Arduino stepper-control path,
tip rack expectations, and the CubOS implementation that maps the legacy
PANDA-BEAR OT2 pipette functions into current protocol commands.

## What The Pipette Setup Does

The setup mounts an Opentrons electronic pipette on the PAW/OT2 backboard and
drives the pipette plunger through the PANDA Arduino firmware. CubOS moves the
gantry to source, destination, tip-rack, and tip-disposal coordinates, then sends
serial commands to the Arduino for plunger actions such as home, aspirate,
dispense, blowout, mix, pick-up-tip, and drop-tip.

The CubOS code path is implemented, but the OT2 pipette hardware path has not
yet been validated on the physical machine in this checkout. Treat every
position, model constant, and serial command as a commissioning value until it
has been tested with the installed pipette, tip rack, and firmware.

## Standalone BOM

Quantities are for one OT-2 pipette station unless noted.

| Qty | Item | Use | Part number / spec | Source | Cost in repo |
| --- | --- | --- | --- | --- | --- |
| 1 | OT-2 single-channel electronic pipette | Liquid handling instrument | P300, `999-00003` in legacy BOM | [Opentrons](https://opentrons.com/products/single-channel-electronic-pipette-p20) | USD 2,750 |
| 1 | Arduino Uno SMD R3 | Serial control path to PAW firmware | `A000073` | [DigiKey](https://www.digikey.com/en/products/detail/arduino/A000073/3476357) | USD 26.30 |
| 1 | Adafruit TMC2209 stepper motor driver breakout | Drives the OT-2 pipette stepper motor | Adafruit `6121` | [Adafruit](https://www.adafruit.com/product/6121) | USD 17.90 |
| 1 | 10-pin socket/socket IDC cable, 6 in | Connection to the OT-2 pipette | Adafruit `370` | [Adafruit](https://www.adafruit.com/product/370) | USD 2.00 |
| 1 | Uno R3 proto shield or equivalent | PAW control circuitry | Legacy BOM used Adafruit `2077`; Cubware capper guide notes a generic Uno R3 protoshield alternative | [Adafruit](https://www.adafruit.com/product/2077) | USD 9.95 |
| 1 pack | Aluminum SMT heat sinks, 10-pack | Heat sink for the TMC2209 stepper driver | Adafruit `1515`, 0.27" x 0.27" x 0.14" | [Adafruit](https://www.adafruit.com/product/1515) | USD 4.95 |
| 1 set | Jumper wires | Arduino/protoshield wiring | Female-female `4447`, extension `4635`, male-male `4482` | [Adafruit 4447](https://www.adafruit.com/product/4447), [Adafruit 4635](https://www.adafruit.com/product/4635), [Adafruit 4482](https://www.adafruit.com/product/4482) | USD 9.95, USD 11.95, USD 9.95 |
| 1 | USB extension cable | Communication with PAW hardware | 10-15 ft USB extension, UPC `686878976212` | [Amazon](https://a.co/d/3PqFbSj) | USD 8.99 |
| 1 kit | M3-M6 bolt kit | Mounting hardware for PAW/backboard parts | Kwokker M3-M6 bolt kit, 20 sizes | [Amazon](https://www.amazon.com/gp/product/B0CLZC8SQ5/) | USD 23.99 |
| As needed | Opentrons-compatible tips | Disposable pipette tips | Match the installed pipette model and tip rack geometry | Opentrons or equivalent | Not listed |

## Printed / Fabricated Parts

| Qty | Part | File | Notes |
| --- | --- | --- | --- |
| 1 | OT2 backboard mount | [`../cubxl_plus/instrument_mounts/backboard/`](../cubxl_plus/instrument_mounts/backboard/) | Main backboard that bolts to the OT-2 frame and carries the PAW-V2 mounts |
| 1 set | OT2 mount spacers | [`../cubxl_plus/instrument_mounts/backboard/`](../cubxl_plus/instrument_mounts/backboard/) | Sets the backboard standoff from the OT-2 frame |
| 1 | Legacy PAW-V2 OT2 mount | [`../cubxl_plus/instrument_mounts/backboard/PAW-V2 - OT2Mount_REV. 1 - OT2Mount.stl`](../cubxl_plus/instrument_mounts/backboard/PAW-V2%20-%20OT2Mount_REV.%201%20-%20OT2Mount.stl) | Cubware STL copy of the legacy PANDA-BEAR OT2 mount |
| 1 | Tip rack | [`../cubxl_plus/labware/tip_rack_holder/`](../cubxl_plus/labware/tip_rack_holder/) | CubOS tip-rack labware definition includes `tip_length`, pickup slots, and consumed-tip tracking |
| 1 | Used-tip disposal target | CubOS deck YAML `tip_disposal` labware | Needed for `drop_tip` protocol commands |

## Mount The Pipette

1. Print the OT2 backboard and spacer parts from
   [`../cubxl_plus/instrument_mounts/backboard/`](../cubxl_plus/instrument_mounts/backboard/).
2. Bolt the backboard to the OT-2 frame and confirm the plate is rigid before
   adding the pipette.
3. Mount the Opentrons pipette with the PAW-V2 OT2 mount hardware.
4. Route the pipette cable and Arduino USB cable so they cannot enter the
   gantry travel envelope.
5. Install the tip rack and used-tip disposal target on the deck.
6. Confirm the pipette nozzle can reach the intended tip-rack, source, and
   destination positions without the pipette body, cable, or backboard colliding
   with the deck or neighboring tools.

The legacy PANDA-BEAR checkout contains only the OT2 mount STEP file and wiring
evidence for this assembly. It does not contain a full mechanical drawing with
all fastener lengths, cable clips, or installation dimensions.

## Wire The Arduino Control Path

The OT2 pipette is controlled by the PAW Arduino firmware, not by the Opentrons
robot API. CubOS talks to the Arduino over serial at `115200` baud by default.

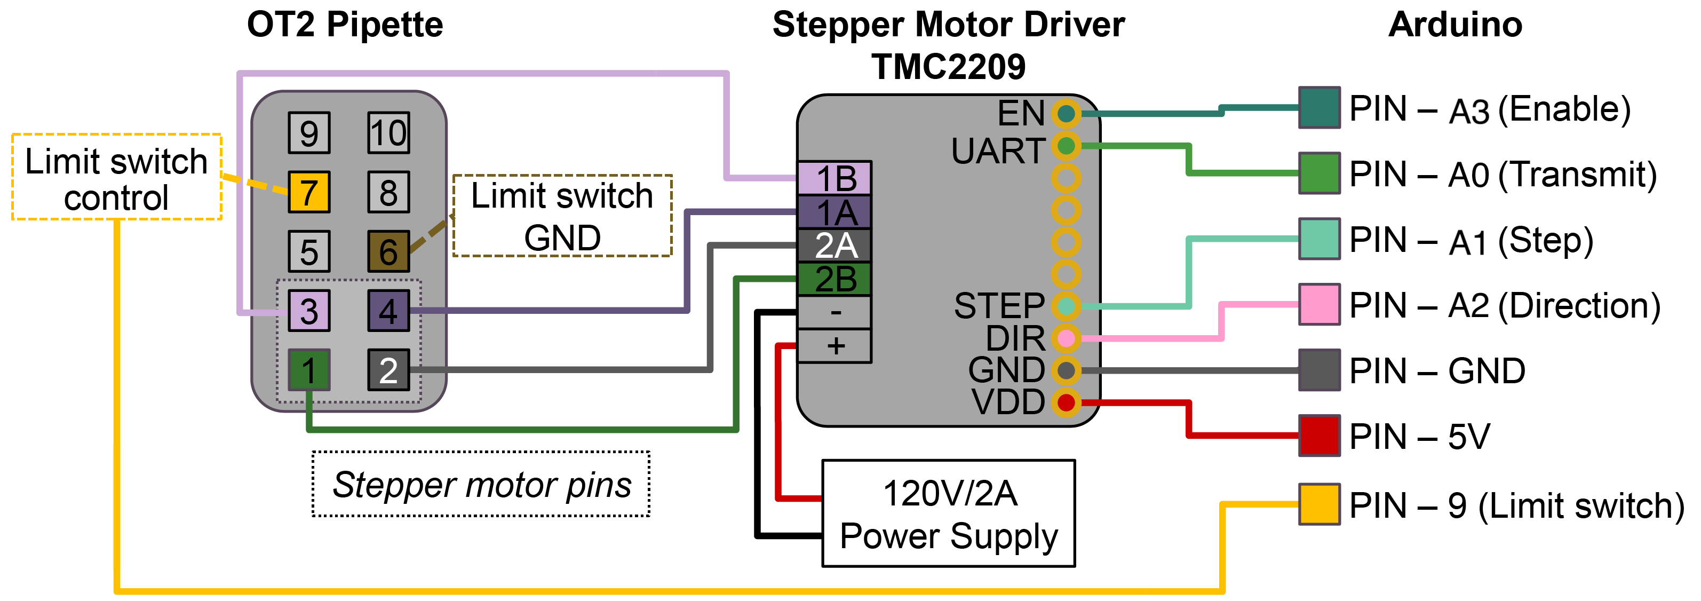
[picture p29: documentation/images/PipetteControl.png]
Pipette control circuit


Use the diagram as the current wiring reference for the Arduino/TMC2209/pipette
control interface. The legacy PANDA-BEAR wiring docs point to the external
[BU-KABlab/PANDA_Arduino](https://github.com/BU-KABlab/PANDA_Arduino)
repository for firmware source, pin assignments, and installation instructions.

### Attach the Heat Sink to the TMC2209

Before wiring the TMC2209 into the control circuit, fit it with the Adafruit
`1515` heat sink so the driver doesn't thermal-throttle or shut down under
sustained plunger moves:

1. Peel the adhesive backing off one heat sink from the Adafruit `1515` pack.
2. Center the heat sink, fins up, over the TMC2209's driver IC (the largest
   chip on the breakout) and press firmly for a few seconds to set the
   thermal tape.
3. Check that the fins clear the breakout's pin headers and don't foul the
   protoshield or neighboring components once seated.

Before running pipette commands:

1. Flash the PAW Arduino firmware that supports the pipette command set.
2. Connect the Arduino to the CubOS host.
3. Identify the serial port, for example `/dev/ttyUSB0`, `/dev/ttyACM0`, or a
   macOS `/dev/tty.usb*` device.
4. Confirm no other process has the serial port open.
5. Keep the pipette clear of tips, liquids, and deck fixtures for the first
   home/status checks.

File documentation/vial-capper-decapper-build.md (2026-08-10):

# Vial Capper / Decapper Build Guide

This page consolidates the current build, wiring, calibration, and validation
notes for the PANDA vial capper / decapper. It covers the custom magnetic vial
caps, the deck vial holder, the PAW-mounted electromagnet, the cap-presence
line-break sensor, and the software checks that prove the mechanism works.

## What The Mechanism Does

The decapper is a PAW tool that uses an electromagnet to pick up a custom vial
cap, lift it off a vial, and later release it back onto the vial. The cap
itself is 3D printed, filled with cured PDMS, and topped with a thin ferrous
metal disc so the electromagnet can hold it.

For PANDA units with `PANDA.version > 1.0`, production capping/decapping code
checks a line-break sensor after each operation. A broken line means the cap is
being held by the decapper; an unbroken line means the cap is not present at the
decapper.

## Standalone BOM

Quantities are for one PANDA vial capper / decapper station unless noted. The
local PANDA BOM does not specify quantities for every PAW subcomponent, so rows
marked "as needed" should be sized to the number of caps/vials or to the
existing PAW build.

### Purchased Parts

| Qty | Item | Use | Part number / spec | Source | Cost in repo |
| --- | --- | --- | --- | --- | --- |
| 1 | Electromagnet | Picks up the ferrous disc in the cap | uxcell 5V 50N; verify part number on listing | [Amazon](https://www.amazon.com/dp/B01NCVII18) | Verify on listing |
| 1 | IR break beam sensor, 5 mm LEDs | Detects whether a cap is present on the decapper | Adafruit 2168 | [Adafruit](https://www.adafruit.com/product/2168) | USD 5.99 |
| 1 | Arduino Uno SMD R3 | Controls PAW peripherals, including the electromagnet and line-break sensor | A000073 | [DigiKey](https://www.digikey.com/en/products/detail/arduino/A000073/3476357) | USD 26.30 |
| 1 | Uno R3 proto shield, generic | PAW control circuitry | HiLetgo Uno R3 ProtoShield with SYB-170 mini breadboard, 2-pack | [Amazon](https://www.amazon.com/dp/B00HHYBWPO) | Verify on listing |
| 1 | MOSFET | Switches the electromagnet from the Arduino control signal | IRLZ44 | [Amazon](https://www.amazon.com/dp/B0CBKH4XGL) | USD 9.99 |
| 1 each | Resistors | Electromagnet circuit | 10 kOhm and 200 Ohm | Not specified | Not listed |
| 1 | Flyback diode | Protects the electromagnet circuit | 1N5819 | [Amazon](https://www.amazon.com/dp/B079KG1TN2) | USD 7.99 |
| 1 set | Jumper wires | Arduino/protoshield wiring | Female-female 4447, extension 4635, male-male 4482 | [Adafruit 4447](https://www.adafruit.com/product/4447), [Adafruit 4635](https://www.adafruit.com/product/4635), [Adafruit 4482](https://www.adafruit.com/product/4482) | USD 9.95, USD 11.95, USD 9.95 |
| 1 | USB extension cable | Communication with PAW hardware | 10-15 ft USB extension, UPC 686878976212 | [Amazon](https://a.co/d/3PqFbSj) | USD 8.99 |
| 1 kit | M3-M6 bolt kit | Mounting hardware for PAW components | Kwokker M3-M6 bolt kit, 20 sizes | [Amazon](https://www.amazon.com/gp/product/B0CLZC8SQ5/) | USD 23.99 |
| As needed | 20 mL stock vials | Vials used with the custom magnetic caps | Fisher 12-100-112 | [Fisher Sci](https://www.fishersci.com/shop/products/clear-voa-glass-vials-0-125in-septa/12-100-112) | Not listed |
| 1 per cap | Adhesive-backed ferrous metal disc | Magnetic target on each custom cap | 25 mm diameter, 0.5 mm height | [Amazon example](https://www.amazon.com/Metal-inch-Replacement-32-Mini/dp/B0CJZ7SLJN/) | Not listed |
| About 2.6 mL per cap | PDMS base and crosslinker | Cured cap insert/seal | 10:1 base:crosslinker | Not specified | Not listed |
| Optional | Super glue | Secures ferrous disc if its adhesive is insufficient | Not specified | Not specified | Not listed |

### Printed / Fabricated Parts

| Qty | Part | File | Notes |
| --- | --- | --- | --- |
| 1 per capped vial, plus spares | Custom 16 mm vial cap | [`3D-prints/VialCap/VialCap16mm.step`](https://github.com/BU-KABlab/PANDA-BEAR/blob/main/documentation/3D-prints/VialCap/VialCap16mm.step) | Print at 0.2 mm layer height; fill with PDMS and add ferrous disc |
| 1 | 20 mL vial holder | [`3D-prints/DeckAccessories/9VialHolder20mL_TightFit.step`](https://github.com/BU-KABlab/PANDA-BEAR/blob/main/documentation/3D-prints/DeckAccessories/9VialHolder20mL_TightFit.step) | Holds vials along the Y-axis |
| 2 | Vial holder pill pins | [`3D-prints/DeckAccessories/9VialHolder20mL_TightFit - Pill.step`](https://github.com/BU-KABlab/PANDA-BEAR/blob/main/documentation/3D-prints/DeckAccessories/9VialHolder20mL_TightFit%20-%20Pill.step) | Construction guide says two are needed to place the holder on the deck |
| 1 | PAW electromagnet mount | [`3D-prints/PAW/PAW-V2 - ElectromagnetMount.step`](https://github.com/BU-KABlab/PANDA-BEAR/blob/main/documentation/3D-prints/PAW/PAW-V2%20-%20ElectromagnetMount.step) | Mounts the electromagnet to the PAW |
| Existing PAW build | PAW body and neighboring tool mounts | [`3D-prints/PAW/`](https://github.com/BU-KABlab/PANDA-BEAR/tree/main/documentation/3D-prints/PAW/) | The capper/decapper assumes the PAW is installed on the gantry |

The closest Cubware part pages are the [vial decapper mount](../cubxl_plus/instrument_mounts/vial_capper_decapper_mount/)
and [9-vial holder](../cubxl_plus/labware/vial_holder/). The legacy PANDA build
assets listed above came from the PANDA-BEAR documentation tree.

## Fabricate The Custom Vial Caps

1. Print [`VialCap16mm.step`](https://github.com/BU-KABlab/PANDA-BEAR/blob/main/documentation/3D-prints/VialCap/VialCap16mm.step)
   at 0.2 mm layer height using the default Bambu Studio profile.
2. If the recessed geometry prints poorly, reduce print speed by 25%.
3. Mix PDMS at 10:1 base:crosslinker.
4. Add about 2.6 mL of mixed PDMS to each cap. The cap has a slightly recessed
   interior fill line.
5. Cure for at least 48 hours. Do not use caps while tacky.
6. If the cap is still tacky after two days, rinse repeatedly with water until
   it is no longer tacky.
7. Place a 25 mm diameter x 0.5 mm adhesive-backed ferrous metal disc into the
   cap's recessed top area.
8. If the disc adhesive is not strong enough, secure it with super glue.
9. Confirm the metal disc is flush with the cap top. No edge or section should
   protrude.

Use caps only for the same solution composition. Some solutions degrade caps
faster than others, so confirm each cap can still be removed by hand before
starting a campaign.

## Install The Vial Holder

1. Print the 20 mL vial holder and two pill pins from the deck accessory files
   listed above.
2. Mount the vial holder on the deck with the pill pins.
3. Place vials along the Y-axis. The construction guide says the first vial has
   the lowest Y value.
4. Calibrate vial locations through the mill calibration menu. The current
   calibration code uses 33.0 mm spacing between vials in the Y-axis when
   recalculating a full holder from the first vial.

## Build And Wire The Decapper

1. Mount the electromagnet to the PAW using the PAW electromagnet mount from
   [`3D-prints/PAW/`](https://github.com/BU-KABlab/PANDA-BEAR/tree/main/documentation/3D-prints/PAW/).
2. Wire the electromagnet through the Arduino-controlled MOSFET circuit with a
   flyback diode. The external firmware currently defines the electromagnet
   output as PWM-capable Arduino Uno pin `11` in `include/Magnet.h`.
3. Install the IR break beam sensor so a cap held by the decapper breaks the
   beam. The external firmware currently defines the line-break sensor input as
   Arduino Uno pin `4` in `include/LineBreak.h`, enables the internal pullup,
   and treats `LOW` as beam broken.
4. Connect the Arduino to the PANDA computer and set the serial port in the
   config.

The repository does not include exact electromagnet mounting dimensions in this
checkout. The PANDA [Arduino wiring guide](https://github.com/BU-KABlab/PANDA-BEAR/blob/main/documentation/Arduino-Wiring.md)
points to the separate
[BU-KABlab/PANDA_Arduino](https://github.com/BU-KABlab/PANDA_Arduino)
firmware repository for firmware, schematics, pin assignments, and installation
instructions.

### Wiring Diagram

This diagram is copied from the PANDA Arduino wiring documentation and shows the
Arduino control system used by the capper/decapper hardware.

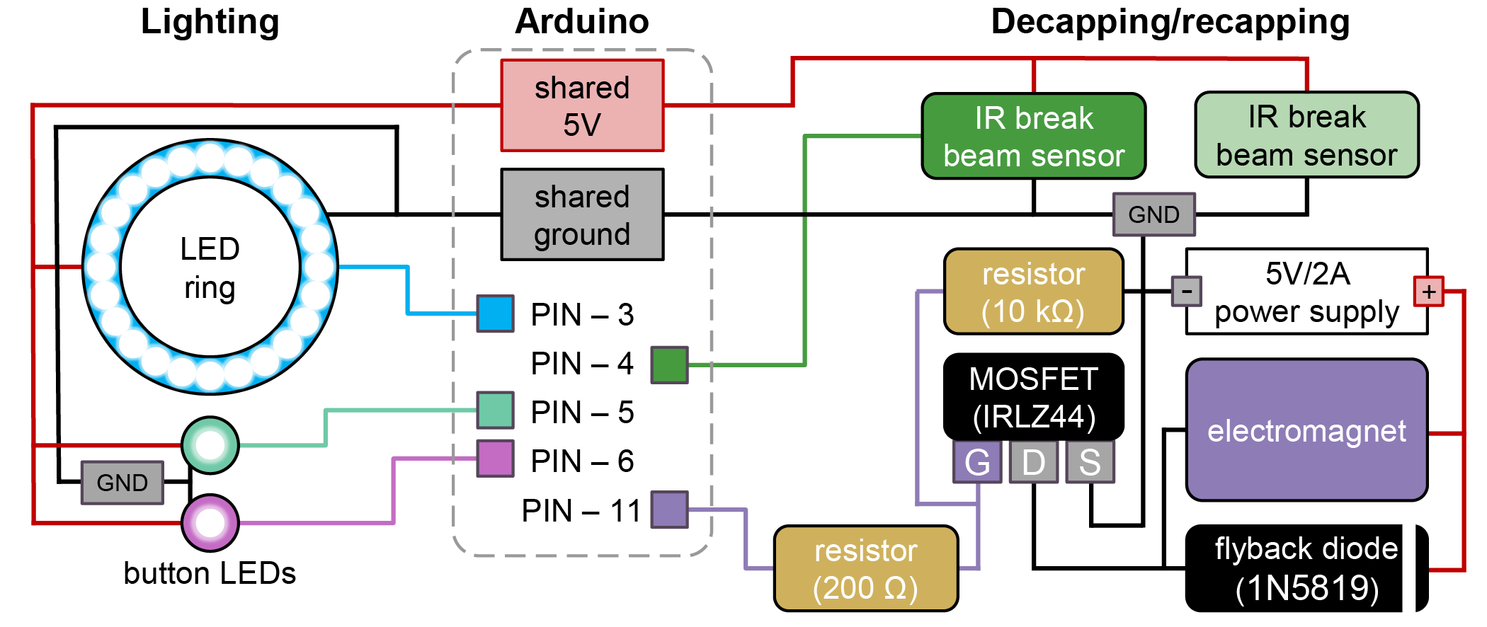
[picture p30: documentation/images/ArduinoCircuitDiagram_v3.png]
Arduino circuit diagram


## Arduino Firmware Details

The external [BU-KABlab/PANDA_Arduino](https://github.com/BU-KABlab/PANDA_Arduino)
repository currently describes itself as firmware for the PANDA Arduino and uses
PlatformIO with:

- `board = uno`
- `framework = arduino`
- `SERIAL_BAUD = 115200`
- Adafruit NeoPixel, ezButton, Adafruit Motor Shield V2, Adafruit PWM Servo
  Driver, AccelStepper, Adafruit BusIO, and TMC2209 dependencies

The firmware entry point `src/pawduino_v2.1.cpp` initializes the interface,
lights, magnet, line-break sensor, and pipette. It also calls
`checkMagnetTimer()` in the main loop. `include/Magnet.h` defines
`MAGNET_TIMER_DURATION` as 5 minutes, so the electromagnet should auto-off after
that duration if left energized.

The firmware's magnet module supports direct duty control, percent control,
full-on/full-off helpers, and `grabCap(holdPct, grabMs)`, which uses a
full-power pickup burst and then drops to a hold duty. The local PANDA-BEAR
Python control path currently uses command `5` (`CMD_EMAG_ON`) through
`no_cap()` and command `6` (`CMD_EMAG_OFF`) through `ALL_CAP()`.

## Arduino Control Contract

Integration into CubOS is in progress.

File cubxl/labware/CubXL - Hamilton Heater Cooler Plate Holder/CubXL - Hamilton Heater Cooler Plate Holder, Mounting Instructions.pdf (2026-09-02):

CubXL - Hamilton Heater Cooler Plate Holder,
Mounting Instructions

Revision History.
Rev. No | Title | Image
0 | CubXL - Hamilton Heater Cooler Plate Holder

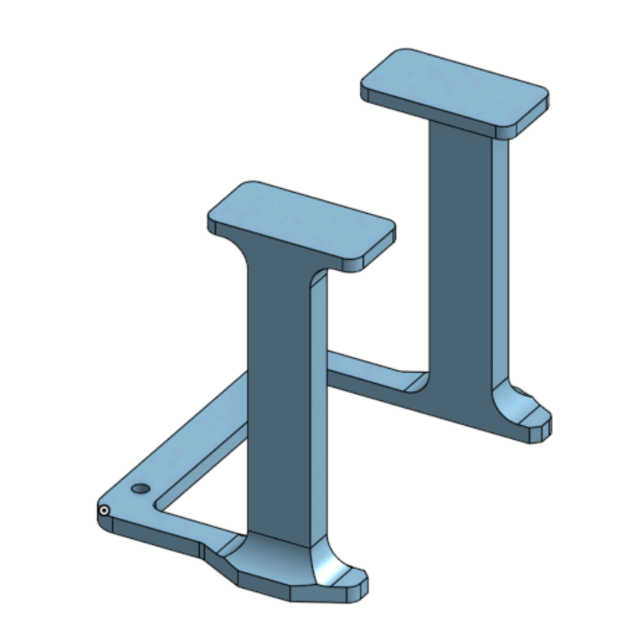
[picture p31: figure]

NOTE: The CubXL - Hamilton Heater Cooler Plate Holder was designed to be used in conjunction with the following component(s):

Item No. | Title | Qty. | Image | Link
1 | Hamilton Heater Cooler (HHC) | 1 | | https://www.ham iltoncompany.co m/temperature-c ontrol/hamilton-h eater-cooler?srsl tid=AfmBOoo_W wFbSwkXBjilc8n hgxbB9zK8E-77 _KORsasTDybY i-Ae43Q9 (https://www.hamiltoncompany.com/temperature-control/hamilton-heater-cooler)
2 | Standard 96 -Position Photoredox Reaction Block, Gen II | 1 | | https://www.analytical-sales.com/product/standard -96-position-phot oredox-reaction-block-gen-ii/?ut m_source=chatg pt.com (https://www.analytical-sales.com/product/standard-96-position-photoredox-reaction-block-gen-ii/)

## Printing CubXL - Hamilton Heater Cooler Plate Holder

NOTE: The CubXL - Hamilton Heater Cooler Plate Holder was originally printed using a Bambu Labs X1-Carbon 3D Printer, with Bambu Lab PLA Basic filament.

NOTE: The default print settings were used with the exception of support generation being turned ON in order to support overhangs. See Figure 1 for a screenshot of support settings.

Figure 1.

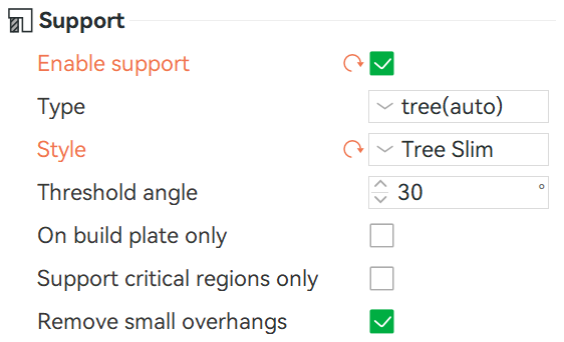
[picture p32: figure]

NOTE: The values in orange were changed from the default settings

## Installation of CubXL - Hamilton Heater Cooler Plate Holder

Required Components.
Item No. | Name | Rev. | Picture | Quantity
1 | CubXL - ASMI Wellplate Holder | 0 | See Revision History | 1
2 | 18-8 SS Button Head Screw, M5, 15mm | N/A | | 2
3 | Zinc Plated Steel Hex Nut, M5 | N/A | | 2

STEP 1. Align the CubXL - Hamilton Heater Cooler Plate Holder in the desired location on the gantry baseplate, ensuring that the two (2) mounting holes align with the holes on the baseplate of the gantry.
STEP 2. Place two (2) 18-8 SS Button Head Screws, M5, 15mm through the aligned mounting and baseplate holes. See Figure 2 for reference.

Figure 2.

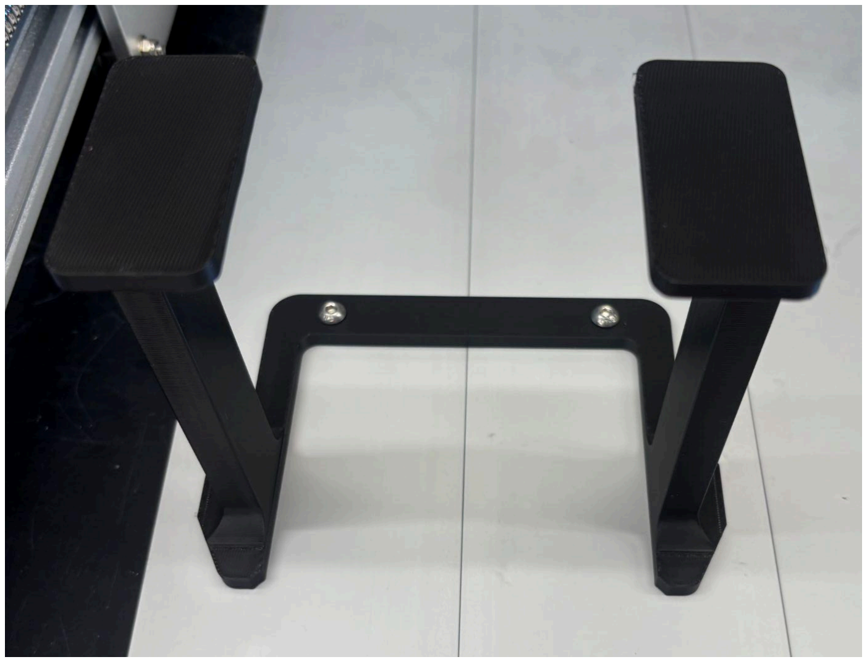
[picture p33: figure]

NOTE: Figure 2 depicts REV. 0 of the CubXL - Hamilton Heater Cooler Plate Holder.

STEP 3. Fasten two (2) Zinc Plated Steel Hex Nuts, M5 onto the two (2) 18-8 SS Button Head Screws, M5, 15mm from underneath the baseplate of the gantry. Tighten the nuts until they are snug and the mount does not move. See Figure 3 for reference.

Figure 3.

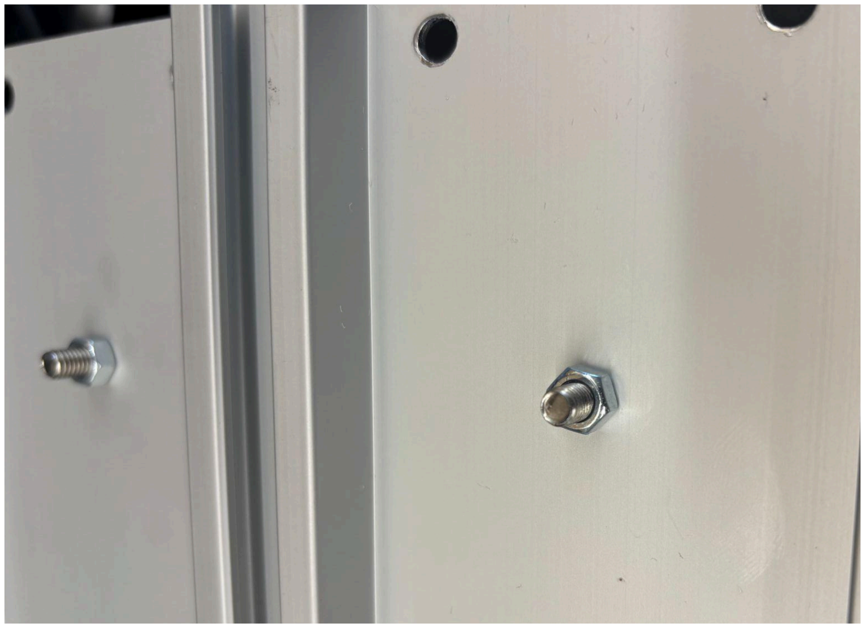
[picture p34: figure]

NOTE: Figure 3 depicts the underside of the gantry baseplate with the nuts installed on the screws.

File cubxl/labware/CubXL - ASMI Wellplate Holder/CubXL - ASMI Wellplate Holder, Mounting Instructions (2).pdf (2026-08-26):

CubXL - ASMI Wellplate Holder,
Mounting Instructions

Revision History.
Rev. No | Title | Image | BOM
0 | CubXL - ASMI Wellplate Holder | | N/A

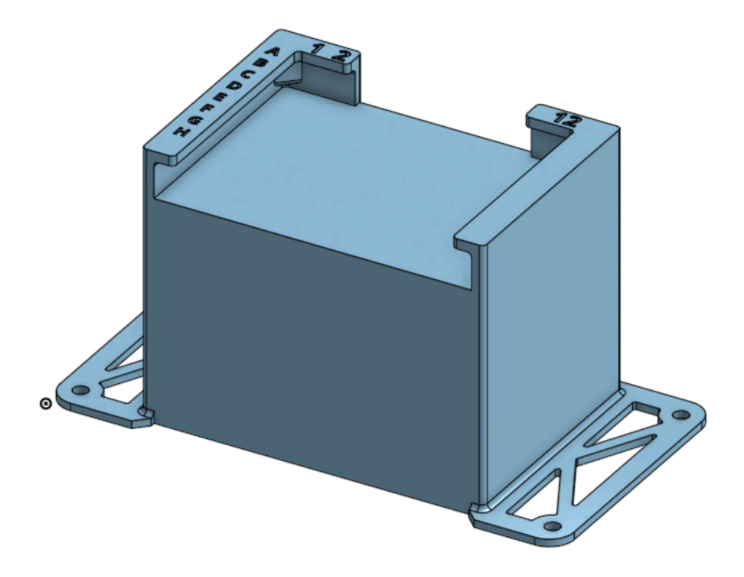
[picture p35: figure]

1 | CubXL - ASMI Wellplate Holder | | N/A

NOTE: The CubXL - ASMI Wellplate Holder was designed to be used in conjunction with the following component(s):

Item No. | Title | Qty. | Image | Link
1 | Cell Culture Microplate, 96 Well, PS, F-Bottom | 1 | | https://shop.gbo.com/en/usa/products/bioscience/cell-culture-products/cellstar-cell-culture-microplates/96-well-cell-c ulture-microplate s-clear/655160.h tml (https://shop.gbo.com/en/usa/products/bioscience/cell-culture-products/cellstar-cell-culture-microplates/96-well-cell-culture-microplates-clear/655160.html)

## 3D Printing CubXL - ASMI Wellplate Holder

NOTE: The CubXL - ASMI Wellplate Holder was originally printed using a Bambu Labs X1-Carbon 3D Printer, with Bambu Lab PLA Basic filament.

NOTE: The default print settings were used with the exception of support generation being turned ON in order to support overhangs. See Figure 1 for a screenshot of support settings.

Figure 1.


NOTE: The values in orange were changed from the default settings

## Installation of CubXL - ASMI Wellplate Holder

Required Components.
Item No. | Name | Rev. | Picture | Quantity
1 | CubXL - ASMI Wellplate Holder | 0-1 | See Revision History | 1
2 | 18-8 SS Button Head Screw, M5, 15mm | N/A | | 4
3 | Zinc Plated Steel Hex Nut, M5 | N/A | | 4

STEP 1. Align the CubXL - ASMI Wellplate Mount in the desired location on the gantry baseplate, ensuring that the four (4) mounting holes align with the holes on the baseplate of the gantry.
STEP 2. Place four (4) 18-8 SS Button Head Screws, M5, 15mm through the aligned mounting and baseplate holes. See Figure 2 for reference.

Figure 2.

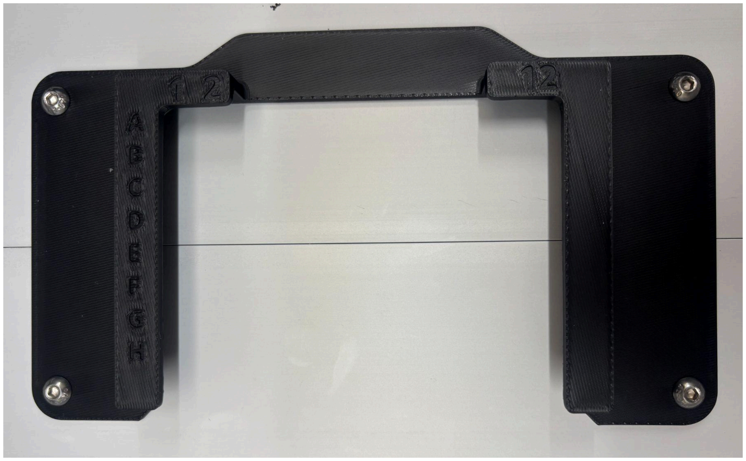
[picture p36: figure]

NOTE: Figure 2 depicts REV. 0 of the CubXL - ASMI Wellplate Holder.

STEP 3. Fasten four (4) Zinc Plated Steel Hex Nuts, M5 onto the four (4) 18-8 SS Button Head Screws, M5, 15mm from underneath the baseplate of the gantry. Tighten the nuts until they are snug and the mount does not move. See Figure 3 for reference.

Figure 3.


NOTE: Figure 3 depicts the underside of the gantry baseplate with the nuts installed on the screws.

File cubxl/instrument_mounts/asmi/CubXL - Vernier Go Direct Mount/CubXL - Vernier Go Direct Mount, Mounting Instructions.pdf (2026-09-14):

CubXL - Vernier Go Direct Mount,
Mounting Instructions
Rev. No | Title | Image | BOM
4 | CubXL - Vernier Go Direct Mount | | See Appendix 1

NOTE: The CubXL - Vernier Go Direct Mount was designed to be used in conjunction with the following component(s):

Item No. | Title | Qty. | Image | Link
1 | Vernier Go Direct Force and Acceleration Sensor | 1 | | https://www.vernier.com/product/go-direct-force-a nd-acceleration-sensor/ (https://www.vernier.com/product/go-direct-force-and-acceleration-sensor/)

## 3D Printing CubXL - Vernier Go Direct Mount

NOTE: The CubXL - Vernier Go Direct Mount was originally printed using a Bambu Labs X1-Carbon 3D Printer, with Bambu Lab PLA Basic filament.

NOTE: The default print settings were used with the exception of support generation being turned ON in order to support overhangs. See Figure 1 for a screenshot of support settings.

Figure 1.


NOTE: The values in orange were changed from the default settings

## Installation of CubXL - Vernier Go Direct Mount

Required Components.
Item No. | Name | Rev. | Picture | Quantity
1 | CubXL - Vernier Go Direct Mount | 4 | | 1
2 | 18-8 SS Socket Head Screw, M4, 16mm | N/A | | 6

3 | 18-8 SS Button Head Screw, M5, 15mm | Only required if using REV. 4 | 2
4 | Zinc Plated Steel Hex Nut, M5 | Only required if using REV. 4 | 2
STEP 1. | Place the Vernier Go Direct Force and Acceleration Sensor into the
rectangular opening of the back half of the Vernier Go Direct Mount, (item no. 1 in BOM). See Figure 2 for orientation of the sensor.

Figure 2.

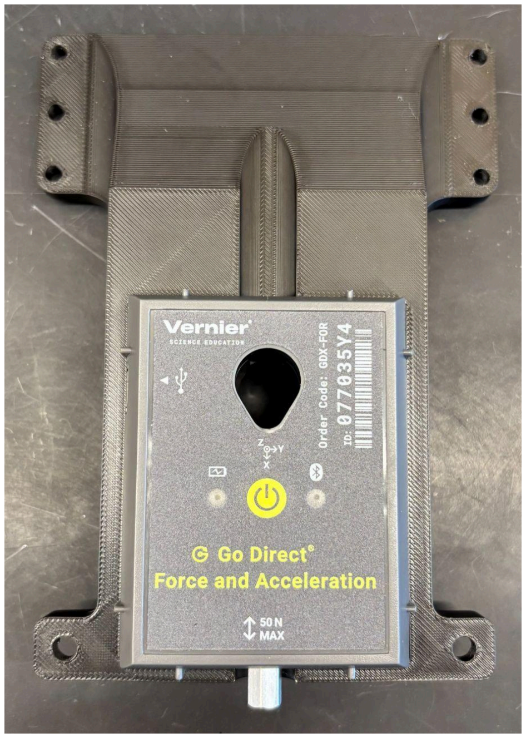
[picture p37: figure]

STEP 2. Place the cover of the Vernier Go Direct Mount (item no. 2 in BOM) onto the assembled sensor and mount, See Figure 3 for reference.

Figure 3.

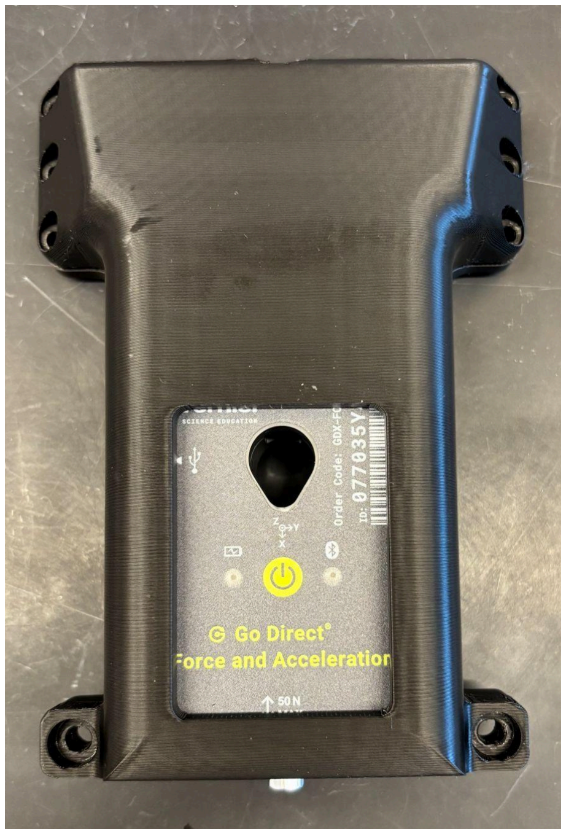
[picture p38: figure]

STEP 3. Place the six (6) 18-8 SS Socket Head Screws, M4, 16mm into the six (6) corresponding holes of the Vernier Go Direct Mount (above the sensor). Then place the two (2) 18-8 SS Button Head Screw, M5, 15mm into the two (2) corresponding holes of the Vernier Go Direct Mount (below the sensor). Place two (2) Zinc Plated Steel Hex Nut, M5 into the hexagon cavities on the backside of the Vernier Go Direct Mount (below the sensor). Using the 3mm Allen Wrench, tighten the two (2) 18-8 SS Button Head Screw, M5, 15mm to the two (2) Zinc Plated Steel Hex Nut, M5 until they are snug and clamping the mount around the force sensor. See Figure 4 for reference.

Figure 4.

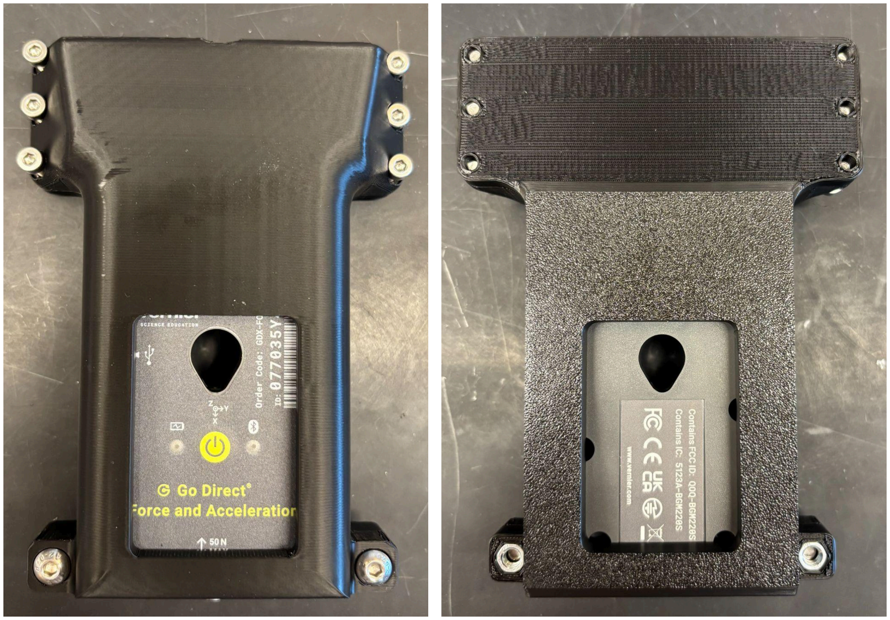
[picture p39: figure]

STEP 4. Align the six (6) 18-8 SS Socket Head Screws, M4, 16mm to the six (6) holes on the X-Axis Module w/ XZ Axis Module/Z-Axis Motor and tighten with the 3mm Allen Wrench until snug. Then plug in the provided cable for the Vernier Go Direct Force and Acceleration sensor into the side of the sensor. See Figure 5 for reference.

Figure 5.

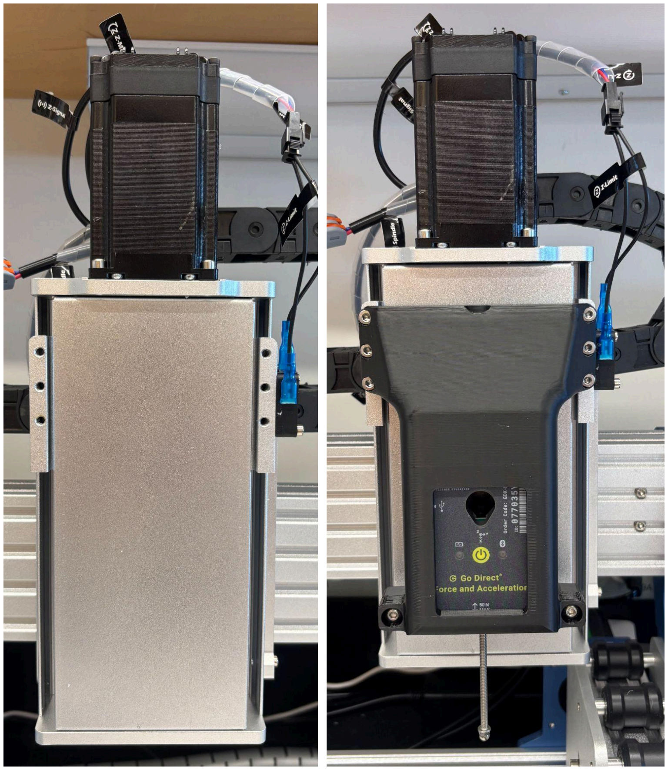
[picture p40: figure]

## Appendix 1

CubXL - Vernier Go Direct Mount_REV. 4 BOM
Item No. | Title | Image | Revision

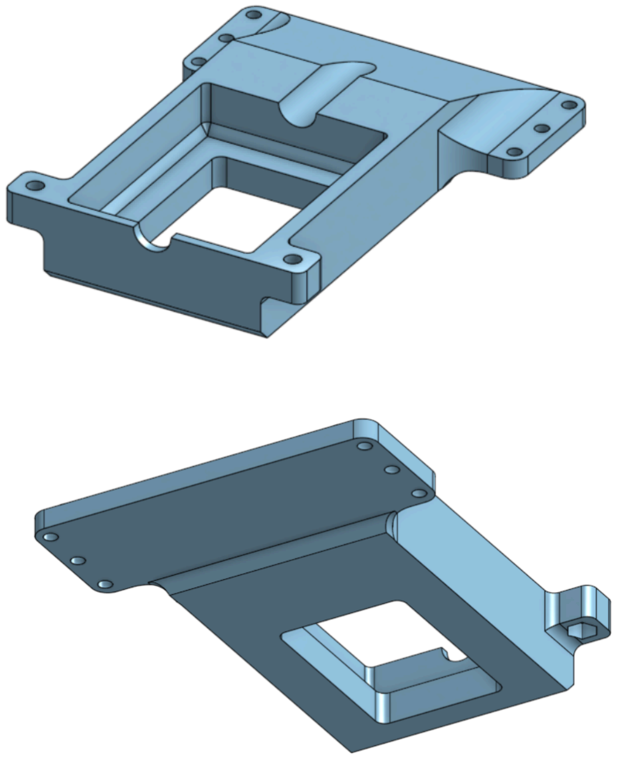
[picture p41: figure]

1 | Vernier Go Direct Mount (Base) | | 4

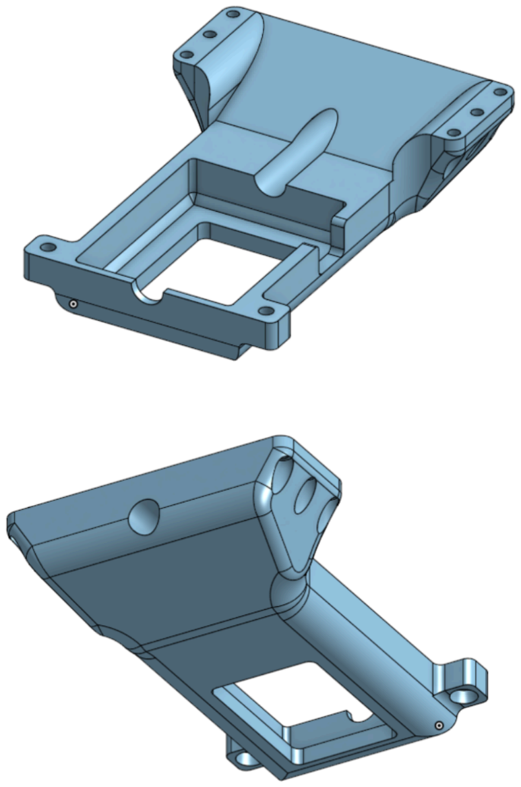
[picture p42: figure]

2 | Vernier Go Direct Mount (Cover) | | 4

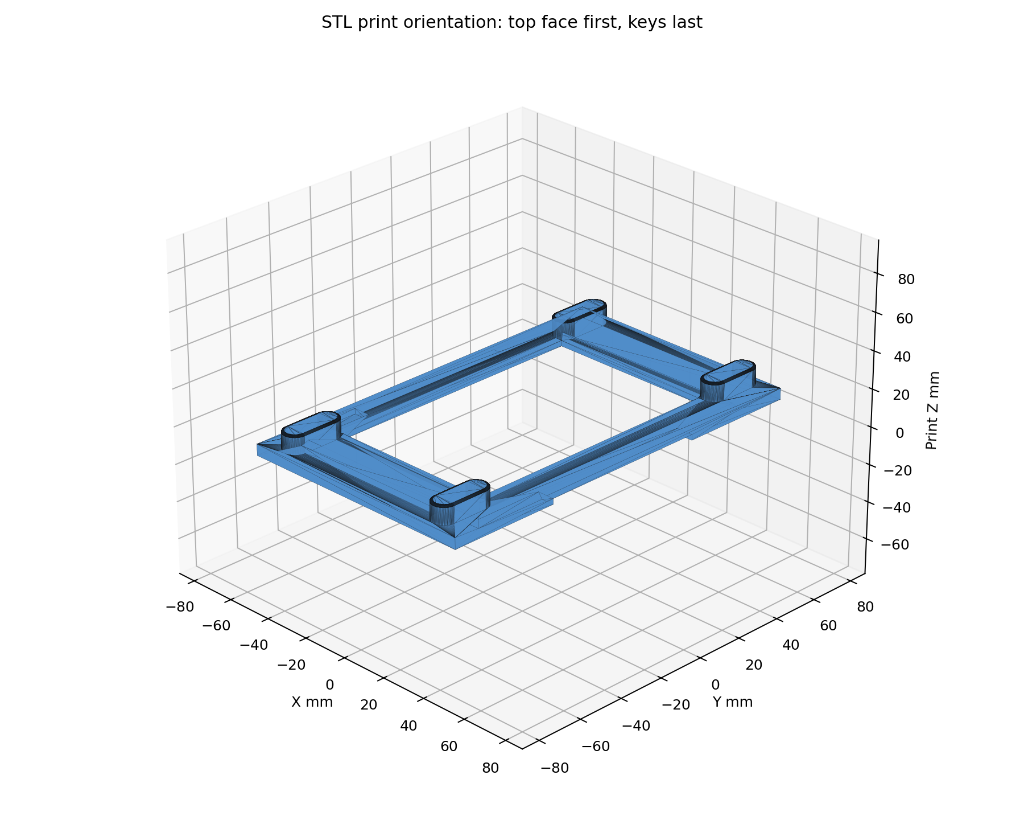
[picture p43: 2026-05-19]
cubxl_plus/labware/well_plate_holder/PandaSBSWellplateHolder-print-orientation.png

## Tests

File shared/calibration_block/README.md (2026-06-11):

# Calibration Bases and Block

3D-printed calibration hardware: three base plates plus a calibration
block, used for establishing reference positions when setting up a Cub
system.

## Files

| File | Purpose |
| --- | --- |
| `Base1.stl` | Calibration base, variant 1. |
| `Base2.stl` | Calibration base, variant 2. |
| `Base3.stl` | Calibration base, variant 3. |
| `Block.stl` | Calibration block. |

## Previews

| Base 1 | Base 2 | Base 3 | Block |
| --- | --- | --- | --- |
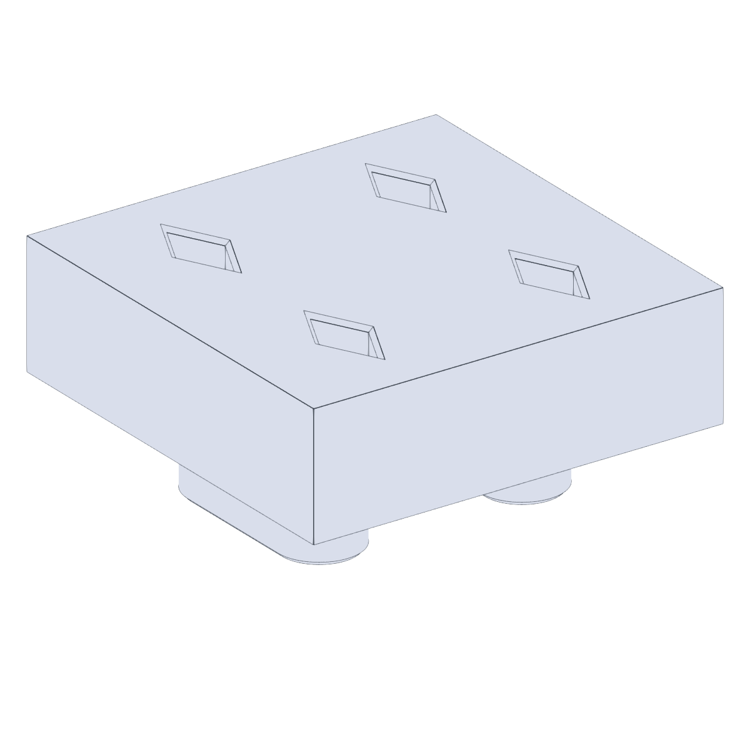
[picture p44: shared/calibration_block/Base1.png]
Base 1
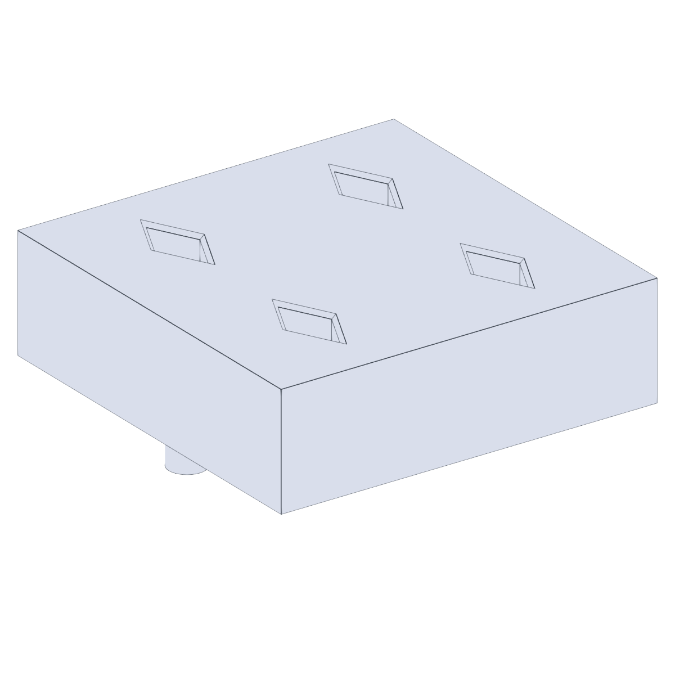
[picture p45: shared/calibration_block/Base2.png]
Base 2
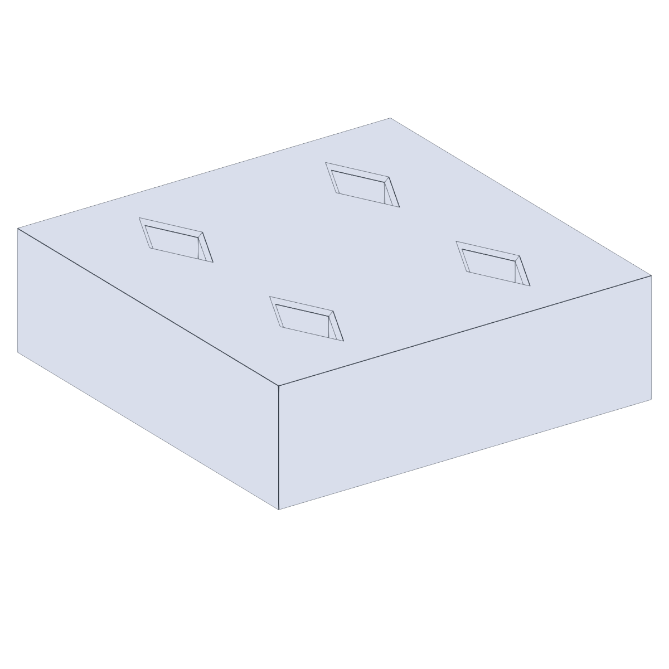
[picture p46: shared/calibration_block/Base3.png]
Base 3
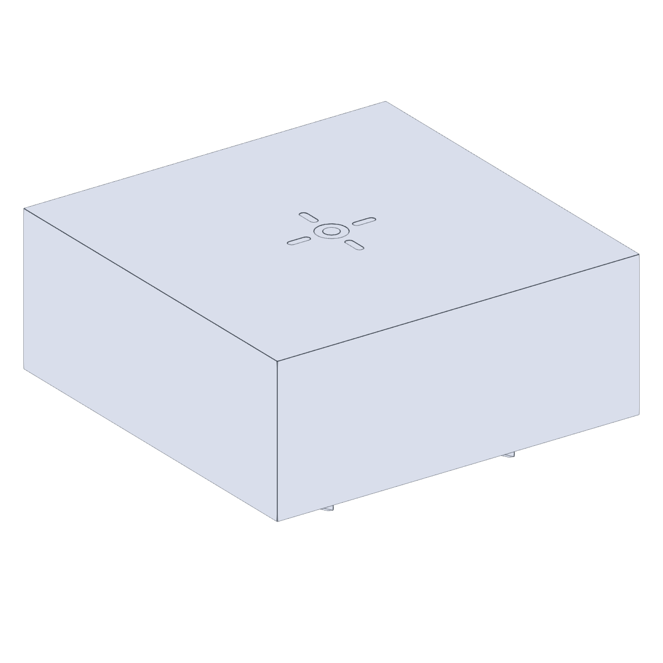
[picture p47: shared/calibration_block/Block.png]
Block
|  |  |  |  |

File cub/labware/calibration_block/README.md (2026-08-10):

# Calibration Bases and Block

Used for establishing reference positions when setting up this Cub
configuration. The printable files are shared by all configurations and
live in [`shared/calibration_block/`](../../../shared/calibration_block/)
— see that README for the file list and previews.

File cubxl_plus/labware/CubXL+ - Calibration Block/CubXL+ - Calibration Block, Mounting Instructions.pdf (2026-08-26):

CubXL+ - Calibration Block,
Mounting Instructions

Revision History.
Rev. No | Title | Image | BOM

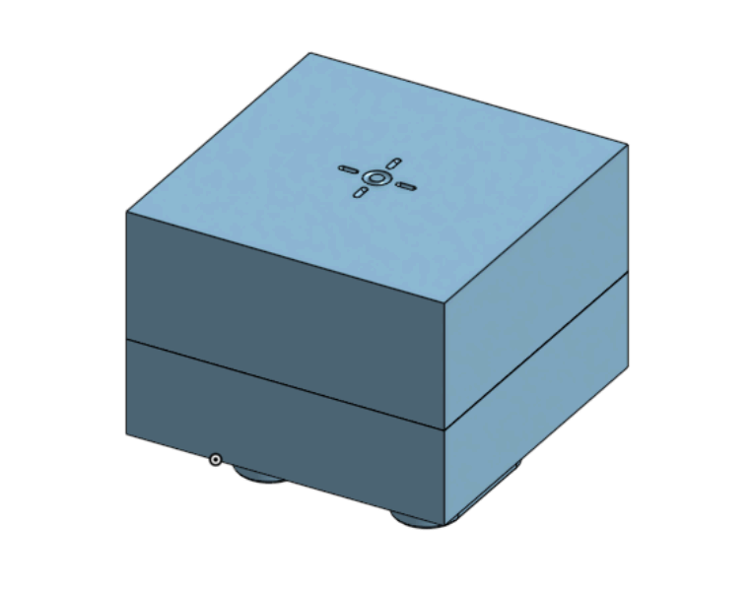
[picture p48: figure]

0 | CubXL+ - Calibration Block | | See Appendix 1

## 3D Printing CubXL+ - Calibration Block

NOTE: The CubXL+ - Calibration Block was originally printed using a Bambu Labs X1-Carbon 3D Printer, with Bambu Lab PLA Basic filament.

NOTE: The default print settings were used with the exception of support generation being turned ON in order to support overhangs. See Figure 1 for a screenshot of support settings.

Figure 1.


NOTE: The values in orange were changed from the default settings

## Installation of CubXL+ - Calibration Block

Required Components.
Item No. | Name | Rev. | Picture | Quantity
1 | Calibration Block | 0 | See Appendix 1 | 1
2 | Calibration Base (CubXL+) | 0 | | 1
STEP 1. | Align the Calibration Base (CubXL+) in the desired location on the gantry
baseplate, ensuring that the two (2) mounting pegs are aligned with two (2) holes on the baseplate of the gantry.
NOTE: Placement of the Calibration Base (CubXL+) is suggested to be in any of the
| four (4) corners of the gantry baseplate.
STEP 2. | Align the four (4) diamond shaped extrusions on the bottom of the Calibration
Block with the corresponding four (4) diamond shaped holes on the top of the Calibration Base (CubXL+).

## Appendix 1

CubXL+ - Calibration Block_REV. 0 BOM
Item No. | Title | Image | Revision

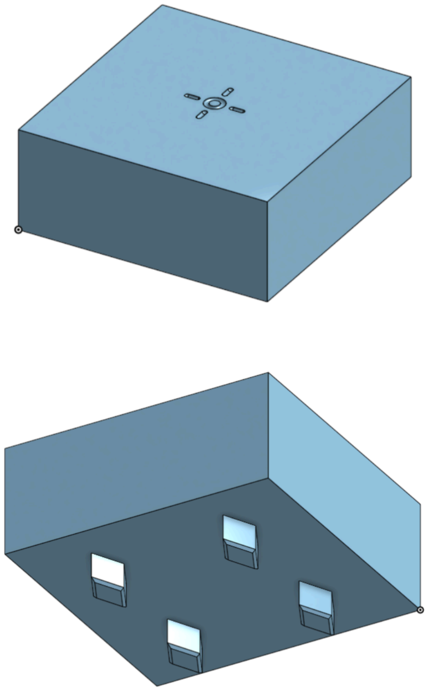
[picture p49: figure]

1 | Calibration Block | | 0

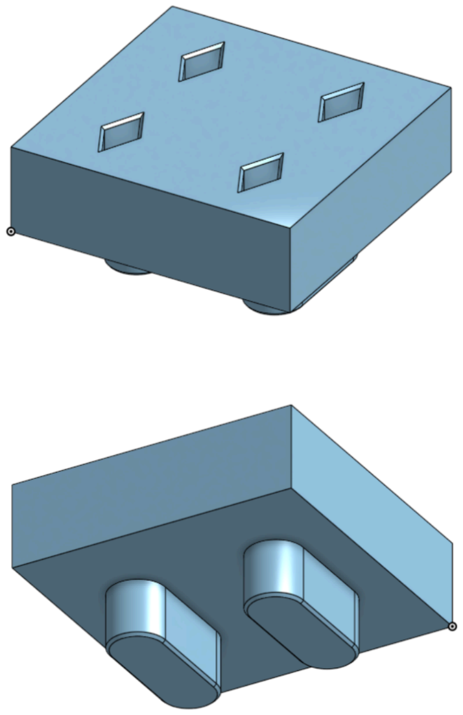
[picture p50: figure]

2 | Calibration Base (CubXL+) | | 0

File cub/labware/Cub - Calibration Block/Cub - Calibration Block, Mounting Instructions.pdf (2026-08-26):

Cub - Calibration Block,
Mounting Instructions

Revision History.
Rev. No | Title | Image | BOM

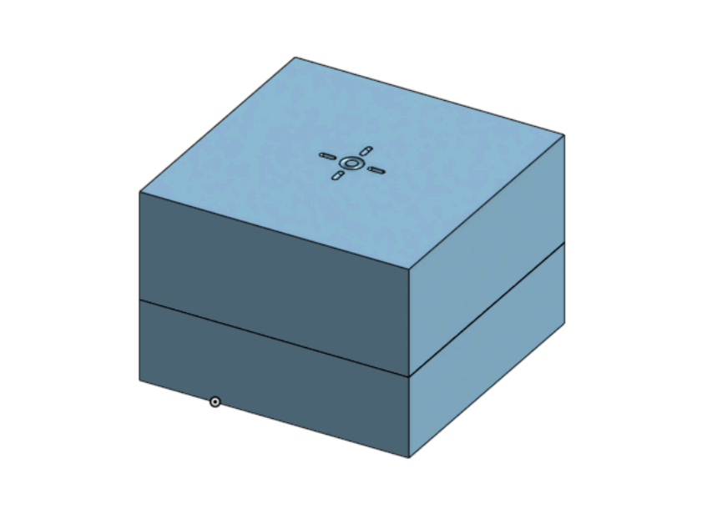
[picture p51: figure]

0 | Cub - Calibration Block | | See Appendix 1

## 3D Printing Cub - Calibration Block

NOTE: The Cub - Calibration Block was originally printed using a Bambu Labs X1-Carbon 3D Printer, with Bambu Lab PLA Basic filament.

NOTE: The default print settings were used with the exception of support generation being turned ON in order to support overhangs. See Figure 1 for a screenshot of support settings.

Figure 1.


NOTE: The values in orange were changed from the default settings

## Installation of Cub - Calibration Block

Required Components.
Item No. | Name | Rev. | Picture | Quantity
1 | Calibration Block | 0 | See Appendix 1 | 1
2 | Calibration Base (Cub) | 0 | | 1
STEP 1. | Align the Calibration Base (Cub) in the desired location on the gantry
baseplate, ensuring that the two (2) mounting pegs are aligned with two (2) holes on the baseplate of the gantry.
NOTE: Placement of the Calibration Base (Cub) is suggested to be in any of the four (4)
| corners of the gantry baseplate.
STEP 2. | Align the four (4) diamond shaped extrusions on the bottom of the Calibration
Block with the corresponding four (4) diamond shaped holes on the top of the Calibration Base (Cub).

## Appendix 1

Cub - Calibration Block_REV. 0 BOM
Item No. | Title | Image | Revision


1 | Calibration Block | | 0

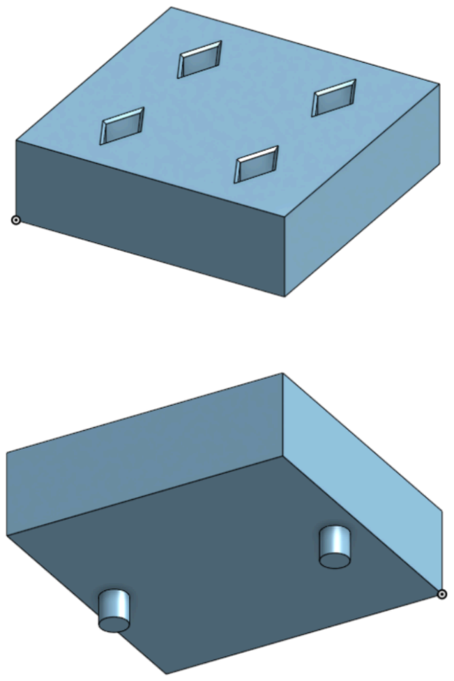
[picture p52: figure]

2 | Calibration Base (Cub) | | 0

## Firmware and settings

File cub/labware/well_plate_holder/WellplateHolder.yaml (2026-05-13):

# WellPlateHolder (deck.labware.well_plate_holder.WellPlateHolder) —
# class-attribute template for the tall wellplate holder.
#
# Every key below maps directly to a field on the WellPlateHolder pydantic
# class. `location` is deliberately omitted; deck YAMLs supply it per-instance.

type: well_plate_holder
name: tall_wellplate_holder
model_name: tall_wellplate_holder
length: 127.5
width: 176.4
height: 25.0
labware_support_height: 25.0
labware_seat_height_from_bottom: 21.0

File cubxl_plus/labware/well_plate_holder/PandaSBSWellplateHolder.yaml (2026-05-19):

# PandaSBSWellplateHolder (deck.labware.well_plate_holder.WellPlateHolder)
#
# Class-attribute template for the keyed PandaDeck SBS 96-well plate holder.
# `location` is intentionally omitted; deck YAMLs supply it per instance.

type: well_plate_holder
name: panda_sbs_wellplate_holder
model_name: PandaSBSWellplateHolder
length: 100.0
width: 164.0
height: 6.0
labware_support_height: 3.0
labware_seat_height_from_bottom: 3.0
well_plate_surface_height_from_bottom: 17.35

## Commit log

2026-05-13 Initialize Cubware with labware from cubos
    Seed the repo with the 3D-printed labware folders copied from
    cubos/src/deck/labware/definitions, organized one folder per part under
    labware/. Add top-level README describing the repo's purpose, layout
    (labware/, gantry/, mounts/), and folder conventions.
    [9VialHolder-key.step, 9VialHolder.step, TipRack.stl]
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2026-05-13 Add ASMI Vernier force sensor mount to mounts/
    Three printable parts (back, front, cap) for housing a Vernier force
    sensor on the ASMI system. Shipped as STL print meshes plus STEP source
    CAD, with a README pointing at the ASMI_new repo for system context.
    [force_sensor_mount_back.step, force_sensor_mount_back.stl, force_sensor_mount_cap.step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]
2026-05-13 Add PandaDeck polycarbonate base plate to gantry/
    Cub-XL base plate for non-contact instruments that reproduces the
    original PANDA-BEAR deck layout. Includes STEP source CAD and an STL
    export, plus a README explaining material, compatibility, and the link
    back to the PANDA-BEAR repo for layout provenance.
    [PandaDeck.step]
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2026-05-13 Correct Cub gantry hardware: PROVER 3030, not Genmitsu
    Cub is built on the SainSmart PROVER 3030, the smaller sibling of the
    4030XL used by CubXL. Update the configurations table accordingly and
    tighten the intro to note that all Cub variants use the PROVER family.
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2026-05-13 Organize new ASMI mounts into per-part folders
    Group the recently pushed PAW-V2 and Opentrons calibration STLs by
    function so each mount has its own folder, matching the convention from
    labware/:
    - opentrons_calibration/ — 3 base plates + calibration block
    - electromagnet_mount/ — REV. 1 (REV. 0 bracket dropped as superseded)
    - raspberry_pi_camera_mount/ — RPi Camera Module 3 mount
    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
    [Opentrons Calibration Base 1 - Part 1.stl, Opentrons Calibration Base 2 - Part 1.stl, Opentrons Calibration Base 3 - Part 1.stl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]
2026-05-13 Promote per-part mount folders out of mounts/asmi/
    These mounts (opentrons calibration, electromagnet, RPi camera, OT2)
    aren't ASMI-specific; they belong directly under mounts/ alongside the
    ASMI Vernier force sensor mount. Move all four folders up one level.
    [Opentrons Calibration Base 1 - Part 1.stl, Opentrons Calibration Base 2 - Part 1.stl, Opentrons Calibration Base 3 - Part 1.stl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]
2026-05-13 Promote ionic conductivity probe mount out of mounts/asmi/
    Same treatment as the other PAW-V2 mounts: it's not ASMI-specific, so
    move it into its own folder directly under mounts/.
    [PAW-V2 - Ionic Conductivity Probe Mount_REV. 0 - Part 1.stl]
2026-05-13 Rename mount folders to reflect their actual roles
    - opentrons_calibration → calibration: the bases/block are general
    calibration hardware, not tied to Opentrons specifically.
    - ot2_mount → ot2_backboard: the OT2-related parts here are the
    backboard (mount plate) plus its spacers, not the OT2 robot itself.
    - electromagnet_mount → vial_decapper_mount: the electromagnet's purpose
    in this system is to drive the vial decapper.
    [Opentrons Calibration Base 1 - Part 1.stl, Opentrons Calibration Base 2 - Part 1.stl, Opentrons Calibration Base 3 - Part 1.stl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]
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2026-05-13 Re-render mount PNGs with VTK; rename ot2/rpi/vial files
    Switch STL preview generation from matplotlib mplot3d to VTK
    (Phong shading, FXAA anti-aliasing, sharp-edge feature splitting at
    30°) so the renders look like real CAD previews instead of faceted
    flat-shaded triangles.
    Rename ot2_backboard, raspberry_pi_camera_mount, and vial_decapper_mount
    parts to PascalCase names that match their folders and drop the
    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
    [OT2Backboard.stl, RaspberryPiCameraMount.stl, Spacers.stl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]
2026-05-13 Flat-fill mount previews; rename calibration + ionic probe files
    Drop Phong lighting from the STL renders — use a constant face color
    plus feature-edge overlay, keeping FXAA anti-aliasing. Result reads
    more like an engineering line drawing than a 3D render, which is
    easier to scan in a folder of similar-looking mounts.
    Also rename the remaining mount files to PascalCase to match folder
    convention and drop the leftover "PAW-V2 -" / "_REV." / "Part 1"
    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
    [Base1.stl, Base2.stl, Base3.stl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]
2026-05-13 Add AGENTS.md, render script, asmi PascalCase rename + previews
    - AGENTS.md documents repo layout, required files per part folder,
    naming conventions (snake_case folders, PascalCase file stems, no
    vendor/REV/Part cruft), and the README template.
    - scripts/render_preview.py checks in the VTK-based preview renderer
    used for the mount PNGs so future parts render consistently.
    - Rename mounts/asmi force_sensor_mount_*.stl/.step to PascalCase
    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
    [ForceSensorMountBack.step, ForceSensorMountBack.stl, ForceSensorMountCap.step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]
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
